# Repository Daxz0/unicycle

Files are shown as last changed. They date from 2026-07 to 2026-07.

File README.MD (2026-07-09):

# About

i was particulary inspired by instagram reels that showed robots demonstrating PID

i have some new members for my VEX Robotics team who are going to be learning about PID soon for their robots, so I wanted a nice way to demonstrate the concept since there are a lot of other variables when tuning a VEX robot.



### Assembly
The following includes which each component in the BOM.csv correlates to the reference on the PCB:

| Reference | Component |
| --- | --- |
| C1 | Aluminum Capacitor (100µF) |
| C2 | Aluminum Capacitor (330µF) |
| C3, C5 | Ceramic Capacitor (22µF) |
| C4, C6, C8, C10  | Ceramic Capacitor (0.1µF)  |
| C7 | Ceramic Capacitor (10nF) |
| C9 | Ceramic Capacitor (2.2nF)  |
| R1 | Resistor (330Ω) |
| R4, R7 | Resistor (4.7kΩ) |
| R5, R6 | Resistor (5.1kΩ) |
| L1 | Power Inductor |
| D1, D4 | Schottky Diode |
| D2 | General Purpose Diode |
| D3 | LED |
| D5 | Schottky Diode (Silicon) |
| U1 | ESP32-S3-MINI-1-N8 |
| U2 | Buck Regulator |
| U3 | LDO Regulator |
| U4 | MPU-6050 (IMU) |
| F1 | Fuse |
| SW1 | Switch |
| J1 | Battery Connector (XT30) |
| J3 | USB-C |
| A1 | Motor Driver |



### Resources
thanks to all these incredible resources that allowed me to put the cad together
- https://grabcad.com/library/nema-17-bracket-1
- https://grabcad.com/library/2s-7-4v-li-po-battery-1
- https://grabcad.com/library/pololu-scooter-skate-wheel-70x25mm-1
- https://a.pololu-files.com/picture/0J5557.600.jpg?7958d675b1fec8d1f6bb65c62e140bbe

note: the adapter for the wheel shaft i made myself as i could not find an existing CAD for it, linked instead is a reference sheet i used to make my own



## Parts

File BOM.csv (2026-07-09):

Material | Cost Per | Amount Needed | Self-provided? | HC Funding | Link
Step Motor Bracket | $1.84 | 1 | No | Yes | https://www.omc-stepperonline.com/nema-17-bracket-for-stepper-motor-and-geared-stepper-motor-alloy-steel-bracket-st-m1
Ceramic Capacitor ( 0.1µF) | $0.34 | 4 | No | Yes | https://www.mouser.com/ProductDetail/KEMET/C0805Y104K1RACTU?qs=2FehpBK1j94DCWpEkocQDw%3D%3D
Aluminum Capacitor (100µF) | $0.01 | 1 | No | Yes | https://us.rs-online.com/product/rs-pro/7111090/70648204/
Aluminum Capacitor (330µF) | $0.269 | 1 | No | Yes | https://www.newark.com/wurth-elektronik/860020373011/capacitor-alu-elec-330uf-16v-radial/dp/99AH1464
Ceramic Capacitor (22µF) | $0.13 | 4 | No | Yes | https://www.digikey.com/en/products/detail/murata-electronics/GRM188R60G226MEA0D/2334877
Resistor (330Ω) | $0.95 | 1 | No | Yes | https://www.pishop.us/product/resistor-330-ohm-16w-5-axial-pack-of-10/
Power Inductor | $5.31 | 1 | No | Yes | https://www.digikey.com/en/products/detail/pulse-electronics/PE-53117NL/2266021
Schottky Diode | $0.29 | 2 | No | Yes | https://www.mouser.com/ProductDetail/Diotec-Semiconductor/1N5819?qs=OlC7AqGiEDlzWAEqP18zhw%3D%3D
General Purpose Diode | $0.17 | 1 | No | Yes | https://www.digikey.com/en/products/detail/diodes-incorporated/1N4148W-7-F/814371
LED | $0.17 | 1 | No | Yes | https://www.digikey.com/en/products/detail/ams-osram-usa-inc/LG-R971-KN-1-0-20-R18/1227925
Schottky Diode (silicon) | $0.51 | 1 | No | Yes | https://www.digikey.com/en/products/detail/comchip-technology/SS34-HF/10279693
ESP32-S3-MINI-1-N8 | $5.43 | 1 | No | Yes | https://www.digikey.com/en/products/detail/espressif-systems/ESP32-S3-MINI-1-N8/15295890
Buck Regulator | $5.22 | 1 | No | Yes | https://www.sicstock.com/products/lm2575-5-0bu-2575-lm2575
LDO Regulator | $0.30 | 1 | No | Yes | https://www.digikey.com/en/products/detail/umw/AMS1117-3-3/17635254
MPU-6050 (IMU) | $12.90 | 1 | No | Yes | https://www.digikey.com.br/en/products/detail/dfrobot/SEN0142/6588492
Fuse | $1.61 | 1 | No | Yes | https://www.digikey.com/en/products/detail/littelfuse-inc/0501010-WRA/8593220
Switch | $0.85 | 1 | No | Yes | https://www.digikey.com/en/products/detail/c-k/JS102011SAQN/401-1999-1-ND/1640114
Battery Connector XT30 | $1.02 | 1 | No | Yes | https://www.lcsc.com/product-detail/plug_Changzhou-Amass-Elec-XT30U-F_C99102.html
USBC Pin | $0.42 | 1 | No | Yes | https://www.lcsc.com/product-detail/USB-Connectors_HCTL-HC-TYPE-C-16P-01A_C2894897.html
Stepper Motor | $10.49 | 1 | No | Yes | https://www.zyltech.com/nema-17-stepper-motor-1-7-a-0-59-nm-84-ozin-1-3-or-5-pack/
Motor Driver | $8.95 | 1 | No | Yes | https://www.pololu.com/product/1182
Wheel | $5.82 | 1 | No | Yes | https://www.pololu.com/product/3272
Shaft/Adaptor | $7.75 | 1 | No | Yes | https://www.pololu.com/product/2673
LiPo Battery | $20.46 | 1 | No | Yes | https://www.amainhobbies.com/protek-rc-2s-lipo-20c-battery-7.4v-2100mah-receiver-battery-ptk-5177/p180515
Resistor (4.7kΩ) | $0.75 | 2 | No | Yes | https://www.adafruit.com/product/2783
Resistor (5.1kΩ) | $0.69 | 2 | No | Yes | https://www.digikey.com/en/products/detail/yageo/SQP500JB-5K1/9167827
Ceramic Capacitor (10nF) | $1.29 | 1 | No | Yes | https://www.newark.com/kyocera-avx/kam32lcg3a103ju/smd-mlc-cap-10nf-1kv-c0g-np0-1210/dp/49AM2069
Ceramic Capacitor (2.2nF) | $0.09 | 1 | No | Yes | https://www.jakelectronics.com/productdetail/murataelectronics-grm1885c1h222ja01d-10224
PCB Fabrication | $~10.00 | 1 | No | Yes | N/A
M3 Screws | $6.99 | 1 | No | Yes | https://www.amazon.com/Screws-Assortment-Plated-Socket-Washers/dp/B0D3X5CT2J
Total: | $114.16

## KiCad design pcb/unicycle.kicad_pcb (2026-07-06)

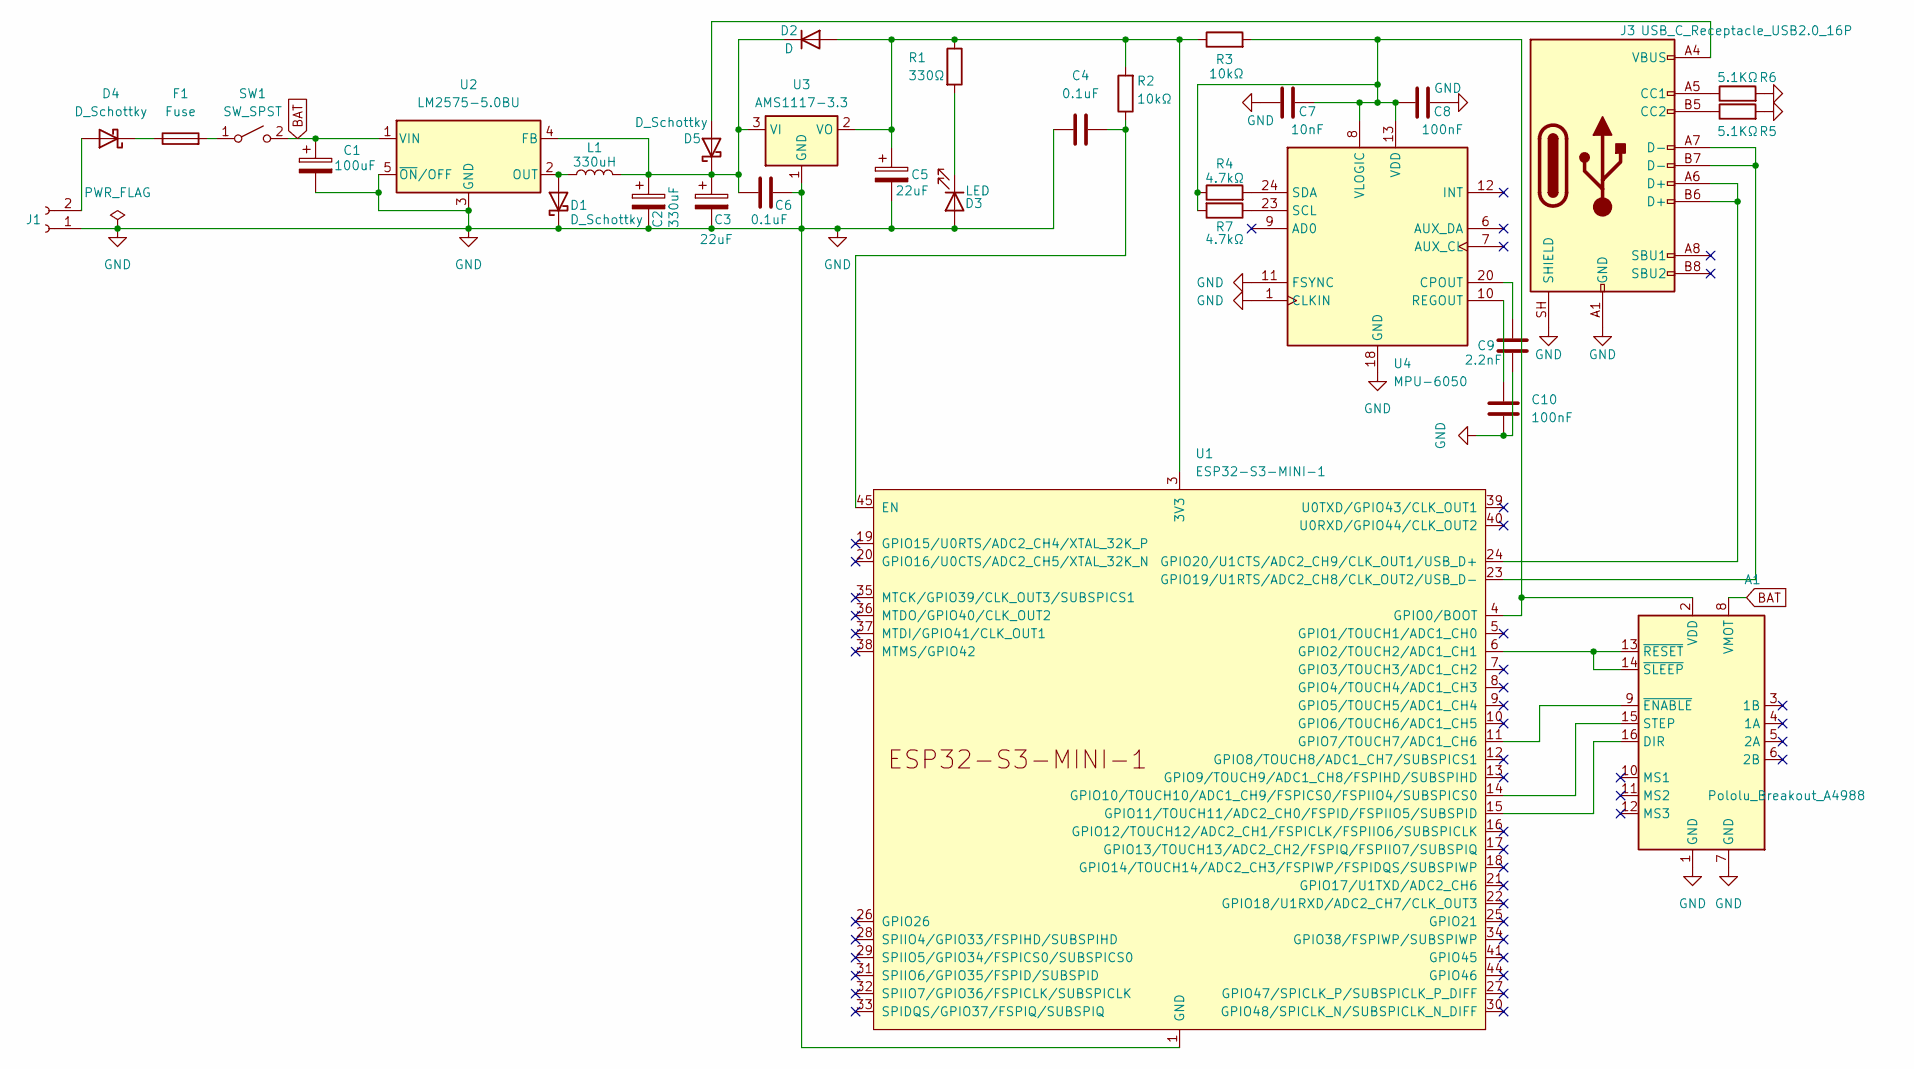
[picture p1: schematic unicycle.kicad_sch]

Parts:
A1: Pololu_Breakout_A4988; Pololu_Breakout-16_15.2x20.3mm
C1: 100uF; CP_Radial_D6.3mm_P2.50mm
C2: 330uF; CP_Radial_D8.0mm_P3.50mm
C3: 22uF; C_0805_2012Metric_Pad1.18x1.45mm_HandSolder
C4, C6: 0.1uF; C_0805_2012Metric_Pad1.18x1.45mm_HandSolder
C5: 22uF; D_0805_2012Metric_Pad1.15x1.40mm_HandSolder
C7: 10nF; C_0805_2012Metric_Pad1.18x1.45mm_HandSolder
C8, C10: 100nF; C_0805_2012Metric_Pad1.18x1.45mm_HandSolder
C9: 2.2nF; C_0805_2012Metric_Pad1.18x1.45mm_HandSolder
D1, D4: D_Schottky; D_DO-15_P15.24mm_Horizontal
D2: D; D_SOD-123F
D3: LED; LED_0805_2012Metric_Pad1.15x1.40mm_HandSolder
D5: D_Schottky; D_SMA
F1: Fuse; Fuse_1206_3216Metric_Pad1.42x1.75mm_HandSolder
J1: Conn_01x02_Socket; AMASS_XT30U-F_1x02_P5.0mm_Vertical
J3: USB_C_Receptacle_USB2.0_16P; USB_C_Receptacle_HCTL_HC-TYPE-C-16P-01A
L1: 330uH; L_Toroid_Vertical_L21.6mm_W11.4mm_P7.62mm_Pulse_KM-3
R1: 330Ω; R_0805_2012Metric_Pad1.20x1.40mm_HandSolder
R2, R3: 10kΩ; R_0805_2012Metric_Pad1.20x1.40mm_HandSolder
R4, R7: 4.7kΩ; R_0805_2012Metric_Pad1.20x1.40mm_HandSolder
R5, R6: 5.1KΩ; R_0805_2012Metric_Pad1.20x1.40mm_HandSolder
SW1: SW_SPST; SW_SPDT_CK_JS102011SAQN
U1: ESP32-S3-MINI-1
U2: LM2575-5.0BU; TO-263-5_TabPin3
U3: AMS1117-3.3; SOT-223-3_TabPin2
U4: MPU-6050; InvenSense_QFN-24_4x4mm_P0.5mm

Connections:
BAT: A1.8 (VMOT), C1.1, SW1.2 (B), U2.1 (VIN)
GND: A1.1 (GND), A1.7 (GND), C1.2, C2.2, C3.2, C4.1, C5.2, C6.1, C7.1, C8.2, C9.2, C10.2, D1.1 (K), D3.2 (A), J1.1, J3.A1 (GND), J3.A12 (GND), J3.B1 (GND), J3.B12 (GND), J3.SH (SHIELD), R5.2, R6.2, U1.1 (GND), U1.2 (GND), U1.42 (GND), U1.43 (GND), U1.46 (GND), U1.47 (GND), U1.48 (GND), U1.49 (GND), U1.50 (GND), U1.51 (GND), U1.52 (GND), U1.53 (GND), U1.54 (GND), U1.55 (GND), U1.56 (GND), U1.57 (GND), U1.58 (GND), U1.59 (GND), U1.60 (GND), U1.61 (GND), U1.62 (GND), U1.63 (GND), U1.64 (GND), U1.65 (GND), U2.3 (GND), U2.5 (~ON/OFF), U3.1 (GND), U4.1 (CLKIN), U4.11 (FSYNC), U4.18 (GND)
unnamed: A1.16 (DIR), U1.15 (GPIO11/TOUCH11/ADC2_CH0/FSPID/FSPIIO5/S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)
unnamed: A1.15 (STEP), U1.14 (GPIO10/TOUCH10/ADC1_CH9/FSPICS0/FSPIIO4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)
unnamed: A1.2 (VDD), C7.2, C8.1, R3.2, R4.1, R7.2, U1.4 (GPIO0/BOOT), U4.8 (VLOGIC), U4.13 (VDD)
unnamed: A1.9 (~ENABLE), U1.11 (GPIO7/TOUCH7/ADC1_CH6)
unnamed: A1.13 (~RESET), A1.14 (~SLEEP), U1.6 (GPIO2/TOUCH2/ADC1_CH1)
unnamed: D1.2 (A), L1.1, U2.2 (OUT)
unnamed: C5.1, D2.2 (A), R1.1, R2.2, R3.1, U1.3 (3V3), U3.2 (VO)
unnamed: C2.1, C3.1, C6.2, D2.1 (K), D5.1 (K), L1.2, U2.4 (FB), U3.3 (VI)
unnamed: D3.1 (K), R1.2
unnamed: D4.2 (A), J1.2
unnamed: D4.1 (K), F1.1
unnamed: D5.2 (A), J3.A4 (VBUS), J3.A9 (VBUS), J3.B4 (VBUS), J3.B9 (VBUS)
unnamed: J3.A5 (CC1), R6.1
unnamed: J3.B5 (CC2), R5.1
unnamed: F1.2, SW1.1 (A)
unnamed: C4.2, R2.1, U1.45 (EN)
unnamed: J3.A7 (D-), J3.B7 (D-), U1.23 (GPIO19/U1RTS/ADC2_CH8/CLK_OUT2/USB_D-)
unnamed: J3.A6 (D+), J3.B6 (D+), U1.24 (GPIO20/U1CTS/ADC2_CH9/CLK_OUT1/USB_D+)
unnamed: C9.1, U4.20 (CPOUT)
unnamed: C10.1, U4.10 (REGOUT)
unnamed: R7.1, U4.23 (SCL)
unnamed: R4.2, U4.24 (SDA)

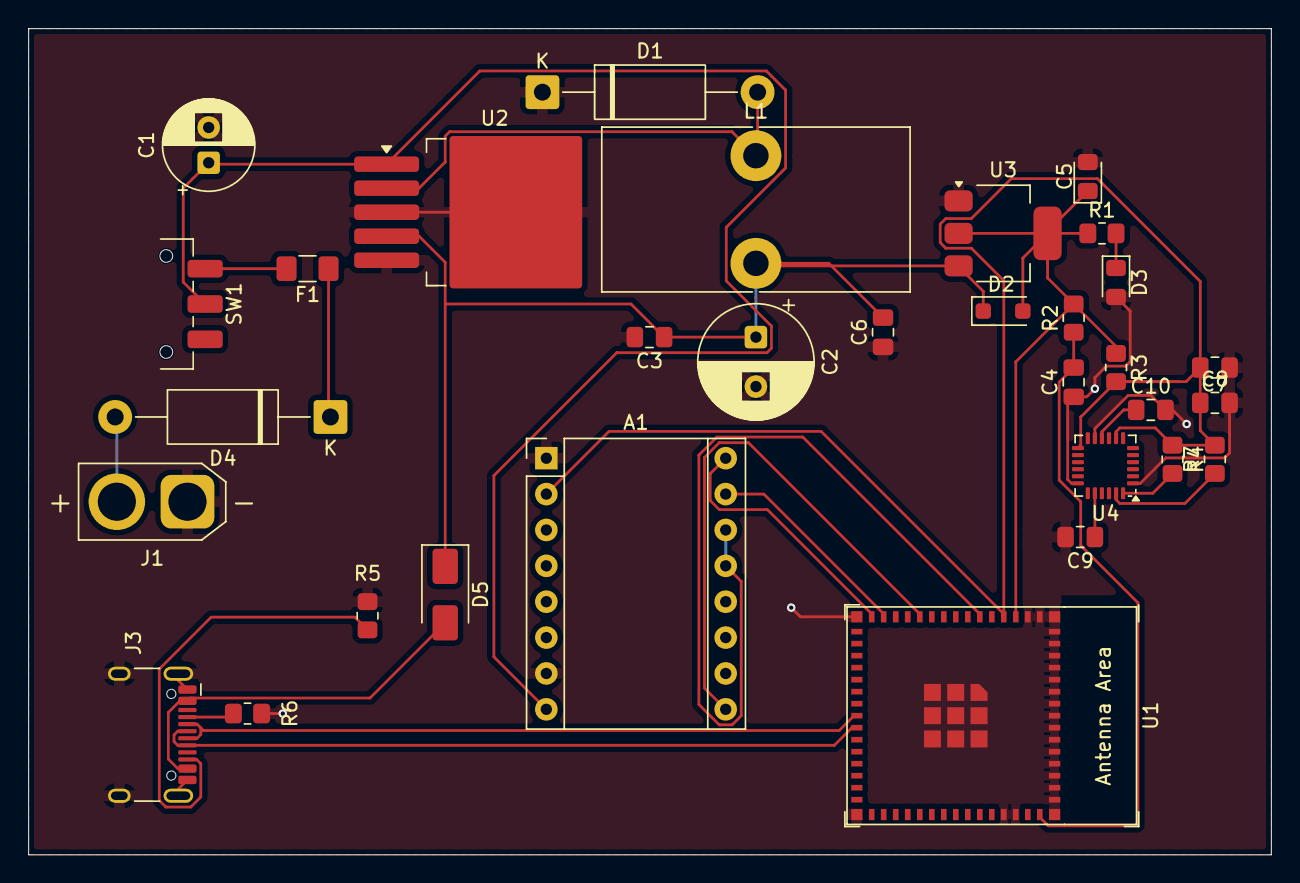
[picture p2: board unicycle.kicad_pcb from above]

Board: 2 copper layers, 88.0 x 58.5 mm, 32 parts (0 on the bottom side), 24 nets.

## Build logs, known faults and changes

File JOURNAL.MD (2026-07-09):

Total time spent: 33hrs

## 7/1/2026 

i saw a cool reel on instagram about pid tuning, and since i already tune my robots pid for VEX, i wanted to just get better at it by using a more extreme example!

im also trying to learn on how to make a pcb, especially since i want to make one later down the road for my battlebot (so its not a jumble of wires)

#### researching the components.
im honestly just going to jump into it, and when the time calls for a specific component, i'll research it as it comes lmao.
i know that i need at least:

- wheel: to ya know be a unicycle
- motor: power that wheel
- IMU: detect when the robot is tilting
- accelerometer: measure which way the robot is tilting
- motor encoder: so i know how much to move the motor
- some sort of microcontroller
- something to control the motors

#### the power portion:
i downloaded kicad, and started just learning some basics of the software, the schematics, and to update the pcb, all that fun stuff

i think the most confusing stuff for me was honestly looking at all the datasheets and stuff since i knew what NOTHING was and where to find say a footprint of something, so that was a challenge in itself.

honestly i feel after finding the datasheet its not that bad!!

i couldnt figure out how to import footprints into kicad so i just tried to find components that didnt require it

anyways here the schematic portion of my power portion before i begin working on anything else


#### the esp!

i managed to import the esp from the library, and setup the EN pin as well as my power/gnd pins.
i also needed the usbc port to flash the esp, so i put that in as well


then i spent some time trying to figure out how to connect the usbc connector and esp together, only the realize that i kinda have to shift everything around to not overlap wires.


hours spent: 7.5hrs

## 7/2/2026

tomorrow came, i slapped on the esc today


read some datasheets and somehow managed to get hopefully the right things wired up, and ERC is telling me no errors so far!!

exciting stuff.

begun to start connecting up the usbc connector so that I can actually flash this said esc


i lowkey like thought that the wires couldnt cross and had a massive crashout about trying to route wires around, but silly me

wired up the usbc connector to the rest of my power source on the 5v channel


lastly to end the night, i wanted to also get in my accelometer, which is going to be the main thing actually letting me know when to correct the PID


hours spent: 5hrs

## 7/4/2026

hi next evening it is.

added onto my drive module for the step motor



i learned about global flags for the first time here, which wouldve really helped earlier but makes it so that theres not a massive wire run all the way from one side to the other (uh yeah you can tell for sure this is my first pcb by how messy my traces are, i know to use flags & power symbols instead in the future)

yayyy i finished up the PCB design, although i ran into a few errors on the way

> Error: J2 pad B11 not found in Connector_USB:USB_C_Receptacle_GCT_USB4085.

this was due to me having like the wrong kind of symbol or something, i swapped it out for a smaller version as per a kicad forum post and no errors! hope it works

-- before


-- after!


i also finally figured out that importing libraries is actually super easy, i just didnt know the right menu for it (which is in the main menu)
i finally imported the ESP32's library and got rid of an error that bugged me:

> Error: Cannot add U1 (footprint 'Espressif:ESP32-S3-MINI-1' not found).

its time to actually take it away from the scheamtic :sob:



tried my best here but i kind of missed things and failed where I didnt fully think about each trace properly, ill look at this with a clearer mind tmr.

hours spent: 6.5hrs

## 7/5/2026

i was lowkey locked in so i missed some images, but i didnt realize a MASSIVE mistake from yesterday



if you compare from yesterday, i was completely missing the ESP32  (the footprint never updated after i imported it i guess)

originally i didnt realize that i could just follow my schematic (yeah kinda dumb i know) but following the actual schematic is so much easier than me trying to figure things out by seeing pad highlights and the rat nests.



i also had to figure out the ground vias and the layers which was pretty straightforward if anything.
the most annoying part i had with DRC is just how when i click the error the highlight is so tiny and i cant see!!

i saved some room on the edges for future holes in the CAD mounting point, which speaking of is time to start up on that.
theres some spoke errors and stuff but googles telling me its a simple fix so i will ignore ignore.

hours spent: 6 hrs

## 7/7/2026

today is the day for CAD!

found grabcad files for the things I need, imported them onto onshape:


trying to figure out battery placements and where to put the PCB, the battery should likely be on the other side of the motor to balance the COG, and the PCB shouldnt matter that much in terms of weight.

hours spent: 2 hrs

## 7/8/2026

i decided to tack on the holes onto the pcb


then got then got the a mounting spot for the battery


i couldnt fing a right mounting spot that matches the holes, so i think ill just hot glue the PCB onto the plastic if it comes to that instead. now the problem is trying to find a suitable spot for the actual pcb since I didnt expect it to be so massive



i mean i could just make it thicker to accomodate the PCB properly


and of course some chamfers + fillets to make everything look good :)



after taking a further look actually, i realized that since i expanded the original platform to allow the PCB to sit properly, i could actually move the battery to be sideways to have even better weight distribution. adding a slit at the top would allow the battery cables to go in properly, i then also need to think of a way to allow myself to put in and take out the battery easily.



actually, in theory the battery shouldnt fall out since the wires up top will be holding it in place and prevent it from pulling out. the other part playing into this is having the exit hole for the battery be higher than the natural sitting position of the battery, since typically the battery should be down due to gravity, making it so that youd have to manually pull up the battery first to take it out.



wrote some preliminary code for the PID controller, well the PID controller doesnt exist yet but i added a foundation to be able to read the IMU and some safety features for when I can begin that.




we have to use the sensitivity from the datasheet (for both the accelerometer and gyroscope) in order to convert the sensor readings into actual units to be usable.

total hours: 7 hrs

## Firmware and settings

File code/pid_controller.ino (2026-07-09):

#include <Wire.h>

#define SDA_PIN         8
#define SCL_PIN         9
#define A4988_RESET_SLP 6
#define A4988_ENABLE    7
#define A4988_STEP      10
#define A4988_DIR       11

#define MPU_ADDR        0x68
#define PWR_MGMT_1      0x6B
#define ACCEL_XOUT_H    0x3B
#define GYRO_XOUT_H     0x43


const float SAFETY_ANGLE = 35.0;



float KP = 1.0;
float KI = 0.0;
float KD = 0.0;




void setup() {
  Serial.begin(115200);
  delay(200);

  pinMode(A4988_RESET_SLP, OUTPUT);
  pinMode(A4988_ENABLE, OUTPUT);
  pinMode(A4988_STEP, OUTPUT);
  pinMode(A4988_DIR, OUTPUT);

  digitalWrite(A4988_RESET_SLP, HIGH);
  disableDriver();

  Wire.begin(SDA_PIN, SCL_PIN);
  Wire.setClock(400000);

  initIMU();

  lastFilterUpdateUs = micros();
  lastPidUpdateUs = micros();
  lastStepUs = micros();

  Serial.println("initialized");
}

void loop() {
  int16_t ax, ay, az;
  int16_t gx, gy, gz;

  readIMU(ax, ay, az, gx, gy, gz);

  float axg = ax / 16384.0;
  float azg = az / 16384.0;

  float angle = atan2(axg, azg) * 180.0 / PI;

  if (abs(angle) < SAFETY_ANGLE && !driverEnabled) {
    enableDriver();
  } 
  else {
    disableDriver();
  }

  delay(10);
}


void initIMU() {
  Wire.beginTransmission(MPU_ADDR);
  Wire.write(PWR_MGMT_1);
  Wire.write(0x00);
  Wire.endTransmission(true);
  delay(100);
}

void readIMU(int16_t &ax, int16_t &ay, int16_t &az, int16_t &gx, int16_t &gy, int16_t &gz) {
  Wire.beginTransmission(MPU_ADDR);
  Wire.write(ACCEL_XOUT_H);
  Wire.endTransmission(false);
  Wire.requestFrom(MPU_ADDR, 14, true);

  ax = (Wire.read() << 8) | Wire.read();
  ay = (Wire.read() << 8) | Wire.read();
  az = (Wire.read() << 8) | Wire.read();
  Wire.read(); Wire.read();  // temperature
  gx = (Wire.read() << 8) | Wire.read();
  gy = (Wire.read() << 8) | Wire.read();
  gz = (Wire.read() << 8) | Wire.read();
}


void enableDriver() {
  digitalWrite(A4988_ENABLE, LOW);
  driverEnabled = true;
}

void disableDriver() {
  digitalWrite(A4988_ENABLE, HIGH);
  driverEnabled = false;
  currentStepRate = 0.0;
}

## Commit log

2026-07-06 added PCB
    [unicycle.kicad_pcb, unicycle.kicad_sch]
2026-07-09 update cad
2026-07-09 chamfered cad
